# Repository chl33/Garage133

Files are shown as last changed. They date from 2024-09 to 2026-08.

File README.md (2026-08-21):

# Garage133

**Garage133** is a DIY garage door automation and monitoring system based on the ESP32.
It provides capability to remotely control up to two garage doors, monitor their
 state (open/closed), detect vehicle presence, measure environmental conditions
 (temperature/humidity), and detect motion within the garage.

The system is designed to integrate seamlessly with **Home Assistant** via MQTT
 but also provides a modern, responsive **Svelte-based Web Interface** for control and configuration.

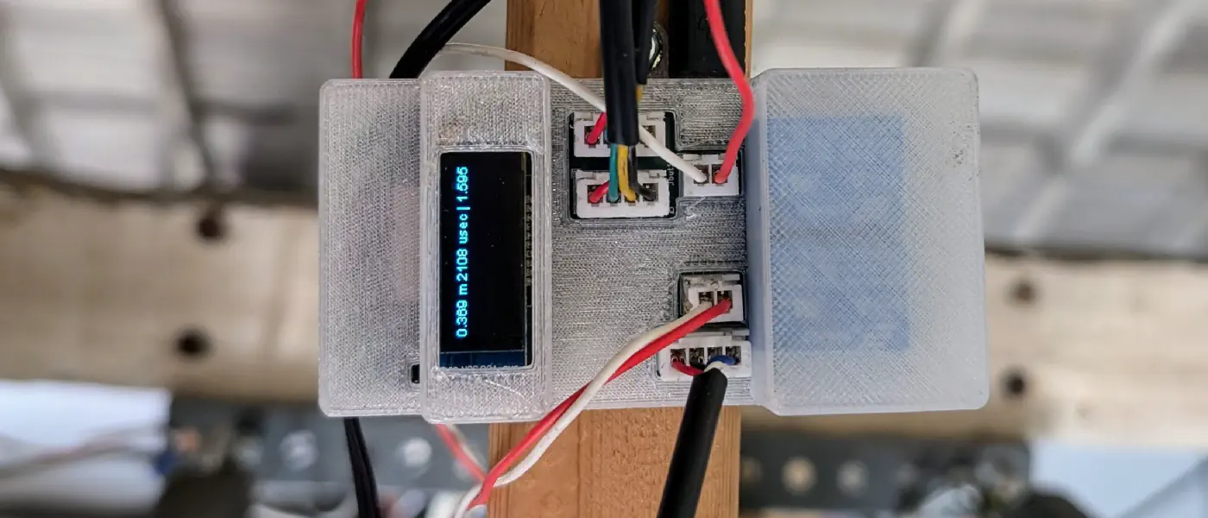
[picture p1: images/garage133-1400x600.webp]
Garage133


## What's New in v1.0.3

*   **Modernized API**: Full transition to `camelCase` JSON keys for all status and configuration endpoints, enabling simpler and more robust integration with the Svelte frontend.
*   **og3 v0.6.0 Core**: Leveraging the latest framework improvements, including declarative `require()` dependencies and optimized memory management.
*   **Automatic Build Pipeline**: Frontend assets are now automatically rebuilt during the PlatformIO compilation process.
*   **Coding and infrastructure cleanups**: Linting, CI, coding improvements.

## Features

*   **Dual Door Control:** Independent control for two garage doors using relays.
*   **HMM State Estimation:** Uses **Hidden Markov Models (HMM)** and sonar sensors to robustly determine door and car states:
    *   **Open** (Door is rolled up).
    *   **Closed with Car** (Door is down, vehicle detected).
    *   **Closed (Empty)** (Door is down, bay is empty).
*   **Modern Web Dashboard:** A responsive Svelte SPA to:
    *   Monitor real-time sensor data and door status.
    *   Trigger door relays remotely.
    *   Visualize HMM detection probabilities.
    *   Manually correct/label states to refine detection.
    *   Upload and reload HMM JSON models dynamically.
*   **Environmental Monitoring:** SHTC3 sensor for Temperature and Humidity.
*   **Motion Detection:** PIR sensor integration.
*   **Light Monitoring:** Analog light sensor to detect garage lighting levels.
*   **Home Assistant:** Native MQTT Discovery support for easy integration.
*   **OLED Display:** Shows status, IP address, and sensor readings locally.
*   **OTA Updates:** Support for reliable Over-The-Air firmware updates using expanded flash partitions.

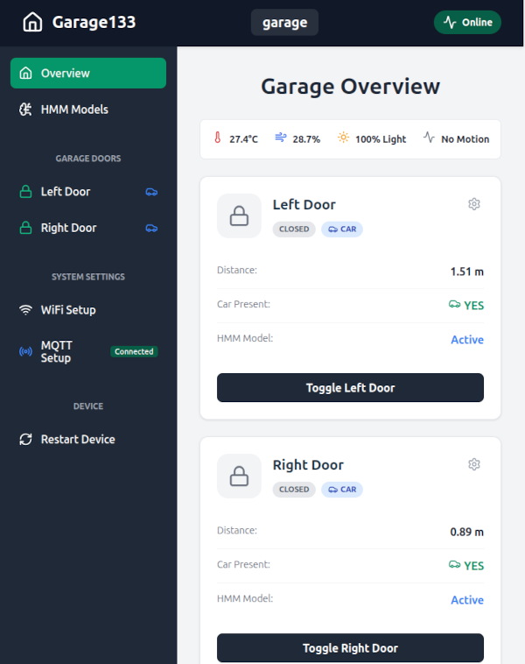
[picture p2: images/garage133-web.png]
Web interface


## Hardware

The project is built around an **ESP32** (Node32s / ESP32 Dev Module).

### Pinout Configuration

| Component | Pin (ESP32) | Description |
| :--- | :--- | :--- |
| **Relay (Left)** | GPIO 15 | Control for Left Garage Door |
| **Relay (Right)** | GPIO 2 | Control for Right Garage Door |
| **Sonar Trigger (Left)** | GPIO 16 | HC-SR04 Trigger |
| **Sonar Echo (Left)** | GPIO 17 | HC-SR04 Echo |
| **Sonar Trigger (Right)** | GPIO 5 | HC-SR04 Trigger |
| **Sonar Echo (Right)** | GPIO 18 | HC-SR04 Echo |
| **PIR Sensor** | GPIO 25 | Motion Detection |
| **Light Sensor** | GPIO 33 | Analog Light Level |
| **I2C SDA** | GPIO 21 | SHTC3 & OLED Display |
| **I2C SCL** | GPIO 22 | SHTC3 & OLED Display |

*Note: Pin definitions can be found in `src/main.cpp`.*

### Fabrication
This repository includes files for fabricating the custom PCB and 3D printed case:
*   **KiCAD:** Circuit board designs are located in the `KiCAD/` directory.
*   **3D Parts:** OpenSCAD and STL files for the enclosure and sensor mounts are
     in the `scad/` directory.

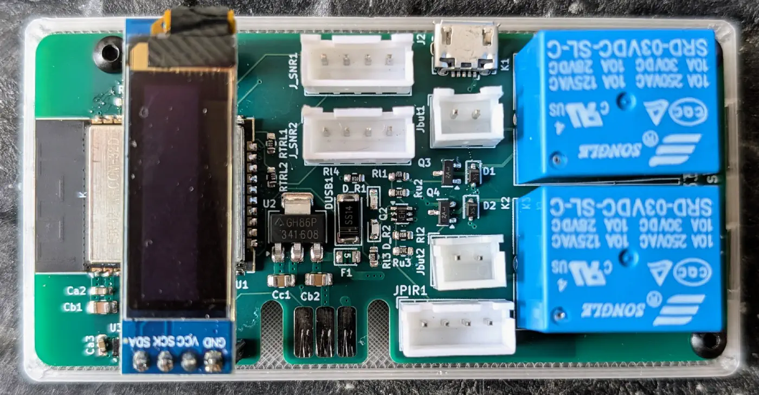
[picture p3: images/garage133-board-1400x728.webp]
Garage133 board

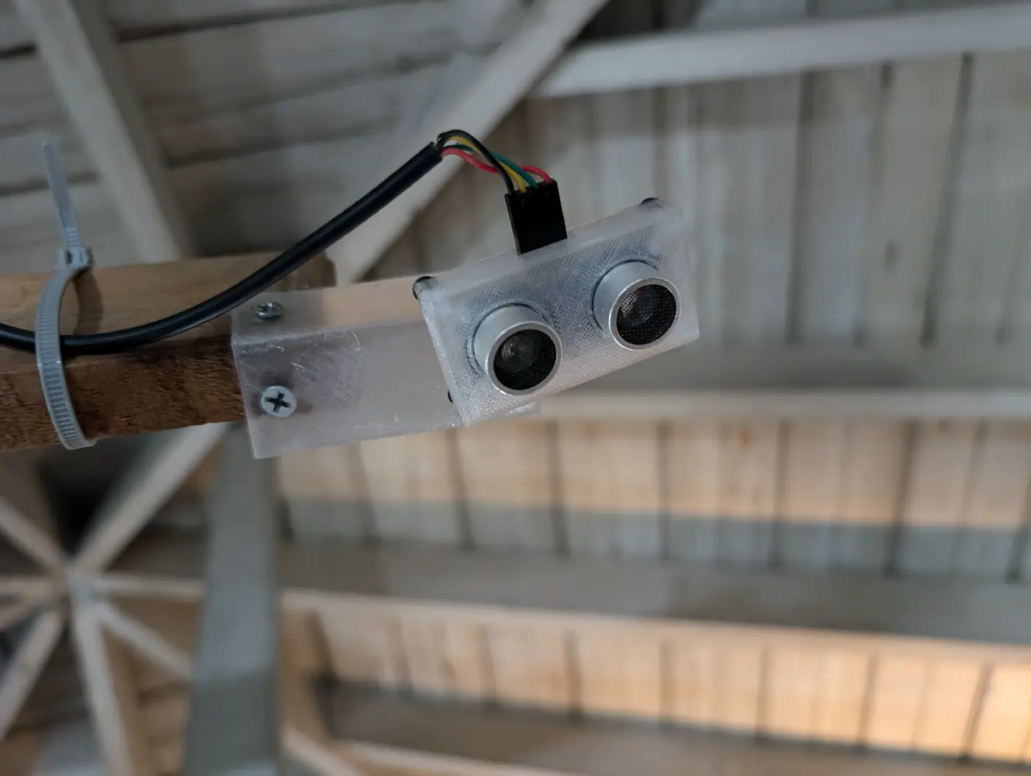
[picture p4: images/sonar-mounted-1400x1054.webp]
Sonar sensor


My sonar sensor mount design is
 [published on printables](https://www.printables.com/model/1741349-sonar-ball-and-socket-mount).

## Getting Started

### Prerequisites
*   [PlatformIO](https://platformio.org/) (VSCode Extension or CLI)
*   [Node.js & npm](https://nodejs.org/) (For building the Web Interface)
*   Git

### Installation

1.  **Clone the repository:**
    ```bash
    git clone https://github.com/chl33/Garage133.git
    cd Garage133
    ```

2.  **Build the Web Interface:**
    Generate the C++ header containing the Svelte assets:
    ```bash
    ./build-svelte.sh
    ```

3.  **Configuration:**
    Copy the example secrets file and configure your environment settings.
    ```bash
    cp secrets.ini.example secrets.ini
    ```
    Edit `secrets.ini` to set your upload port, UDP log target, and OTA password.

-    *Note: WiFi and MQTT credentials can be configured via the captive portal on
-	 first boot, when you attach to the board's WiFi network named 'garage133.'
     They can be configured via the web dashboard therafter.*

4.  **Build and Flash:**
    Connect your ESP32 via USB for the first flash (to apply the `min_spiffs` partition table).
    ```bash
    pio run -e usb_node32s --target upload
    ```

## Usage

### Web Interface
Once connected to WiFi, navigate to the device's IP address in your browser.
*   **Overview:** Real-time status of both doors and environment.
*   **Door Details:** Click the Gear icon on a door card to see HMM probabilities, manually label the current state, or upload a new model.
*   **Settings:** Configure WiFi, MQTT, and restart the device.

### Home Assistant
Ensure your Home Assistant instance has an MQTT broker configured.
The device uses Home Assistant MQTT Discovery. Once the device connects to your MQTT broker, the following entities should automatically appear:
*   **Covers:** `left_door`, `right_door` (Open/Close control)
*   **Sensors:** `temperature`, `humidity`, `light`
*   **Binary Sensors:** `car` (presence for each bay), `motion`

### HMM Analysis Toolkit
The `analysis/` directory contains Python tools to help refine your detection models:
*   Download historical sonar data from InfluxDB, if you have this setup.
*   Train HMM models using the Viterbi algorithm.
*   Evaluate and export models to JSON for upload to the device.

## Blog Post
For a more detailed write-up on the background and design of this project, please see the [blog post](https://selectiveappeal.org/posts/garage133/).

## License
This project is licensed under the MIT License - see the [LICENSE](LICENSE) file for details.

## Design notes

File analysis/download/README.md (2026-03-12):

# InfluxDB Data Downloader

This tool downloads sonar sensor data (or any other entity) from InfluxDB for a specified time range and saves it to a CSV file, suitable for analysis and model training (e.g., HMMs).

## Setup

1.  Navigate to this directory:
    ```bash
    cd analysis/download
    ```
2.  Install dependencies using Poetry:
    ```bash
    poetry install
    ```

## Usage

Run the script via `poetry run`:

```bash
poetry run python src/download/download.py \
    --start "2026-02-01T00:00:00Z" \
    --end "2026-02-25T23:59:59Z" \
    --entity "garage_measured_distance" \
    --output "sonar_training_data.csv"
```

### Parameters:
*   `--start`: ISO8601 start timestamp (UTC).
*   `--end`: ISO8601 end timestamp (UTC).
*   `--entity`: The `entity_id` tag in InfluxDB (default: `garage_measured_distance`).
*   `--output`: Filename for the resulting CSV (default: `sonar_data.csv`).

## Configuration
The script uses the following defaults (found in `download.py`):
*   **Host:** `influxdb.go-robo.net`
*   **Database:** `Home Assistant`
*   **Token:** Can be set via the `INFLUX_TOKEN` environment variable.

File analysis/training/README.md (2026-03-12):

# Garage133 Training Module

This module trains a Hidden Markov Model (HMM) to classify garage states (Open, Closed+Car, Closed+Empty) based on sonar distance readings. It generates side-specific models (`hmm_left.json` and `hmm_right.json`) that can be uploaded directly to the ESP32.

## Setup

Ensure you have Poetry installed, then run:

```bash
poetry install
```

## Training the Model

To train side-specific models using a labeled manifest:

```bash
poetry run python src/training/train_hmm.py --manifest manifest.yaml --output-dir .
```

### Advanced Training Options
*   **Granular Bucketing**: Instead of manual boundaries, you can generate evenly spaced buckets to capture a more detailed "fingerprint" of the garage states.
    ```bash
    poetry run python src/training/train_hmm.py --num-buckets 10 --max-dist 400
    ```
    *   `--num-buckets`: Number of distance ranges to use (e.g., 10).
    *   `--max-dist`: The maximum expected distance in cm (e.g., 400). Readings beyond this will fall into an "Error/Reflection" bucket.
*   **Manual Boundaries**: 
    ```bash
    poetry run python src/training/train_hmm.py --boundaries 70 190 350
    ```

## Testing and Validation

### Individual Episode Test
To visualize the performance on a specific episode:
```bash
poetry run python src/training/test_hmm.py --model-dir . --manifest manifest.yaml --episode 0 --probs
```
*   `--probs`: Show internal state probabilities (confidence) over time.

### Global Performance Characterization
To characterize how well your model performs across **every episode** in your manifest at once:
```bash
poetry run python src/training/test_hmm.py --model-dir . --manifest manifest.yaml --all
```

**What this provides:**
*   **Global Accuracy**: A single percentage representing performance across all your collected data.
*   **Global Confusion Matrix**: An aggregated matrix that highlights systematic errors (e.g., if the model frequently confuses "Car" and "Empty" across multiple days).

### Understanding the Metrics
*   **Accuracy**: The percentage of sonar samples correctly classified.
*   **Confusion Matrix**: Rows represent the actual state (Ground Truth), and columns represent what the HMM predicted.
    *   *Diagonal entries* (top-left to bottom-right) represent correct classifications.
    *   *Off-diagonal entries* show exactly which states are being confused.

## Data Organization

The trainer expects a `manifest.yaml` file that points to CSV files containing sonar data. Use the `interactive.py` tool in the `download` module to generate and label these episodes.

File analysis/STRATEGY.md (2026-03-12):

# Garage133: HMM Classification Strategy

This document outlines the strategy for replacing distance-threshold-based logic with a Hidden Markov Model (HMM) for garage door and car presence classification.

## 1. State Definition
Each side of the garage is modeled independently with three hidden states:
1.  **`OPEN`**: The garage door is rolled up, typically resulting in very close sonar readings (< 60cm).
2.  **`CLOSED_CAR`**: The door is shut and a vehicle is present. Readings are in the middle range (e.g., 80cm – 180cm).
3.  **`CLOSED_EMPTY`**: The door is shut and no vehicle is present. Readings are far (e.g., > 200cm, bouncing off the floor).

## 2. Emission Model: Discrete Buckets
To ensure robustness against sensor noise and ease of implementation on the ESP32, we use **Discrete Emissions**:
*   Raw sonar readings (cm) are mapped into buckets (e.g., 0, 1, 2, 3).
*   **Bucket 0 (Near):** 0 – 70cm
*   **Bucket 1 (Mid):** 70 – 190cm
*   **Bucket 2 (Far):** 190 – 350cm
*   **Bucket 3 (Error/Long):** > 350cm

The HMM learns the probability of seeing each bucket while in each hidden state. For example, in state `OPEN`, the probability of Bucket 0 is very high (~0.95), while Bucket 2 is near zero.

## 3. Transition Model & Priors
Training data consists of short "episodes" (e.g., a car entering). This data is **not representative** of a full 24-hour cycle. To avoid a biased model:
*   **Learn Emissions from Data:** Use the episodes to calculate the mean/variance or bucket distributions for each state.
*   **Hard-code Transitions (Priors):** Manually define the transition matrix based on physical reality:
    *   `CLOSED_EMPTY` cannot transition to `CLOSED_CAR` without passing through `OPEN`.
    *   Stay-probabilities should be high (e.g., 0.999) to provide "hysteresis" and filter out transient sensor errors.

## 4. Data Organization: The Manifest
Training data is managed via a central `manifest.yaml`. This keeps raw CSVs immutable and allows for easy re-labeling.

### Manifest Structure
```yaml
episodes:
  - file: "raw/event_001.csv"
    left:
      initial_state: "closed_empty"
      transitions:
        - { time: "2026-02-27T10:00:05Z", to: "open" }
        - { time: "2026-02-27T10:01:00Z", to: "closed_car" }
    right:
      initial_state: "closed_car"
      transitions: []
```

## 5. Workflow
1.  **Collection:** Use `download.py` to fetch data from InfluxDB. Provide state labels during download to auto-populate the manifest.
2.  **Training:** A Python script reads the manifest, processes CSVs, and calculates HMM parameters (Transition Matrix $A$, Emission Matrix $B$, Initial Probabilities $\pi$).
3.  **Deployment:** Export parameters to a C++ header (`hmm_config.h`) for the ESP32.
4.  **Refinement:** If the ESP32 fails, download that specific time range, label it correctly in the manifest, and retrain.

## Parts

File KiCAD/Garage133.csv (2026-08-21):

Reference | Qty | Value | DNP | Exclude from BOM | Exclude from Board | Footprint
Ca1,Ca2,Ca3 | 3 | 100nF |  |  |  | Capacitor_SMD:C_0603_1608Metric
Cb1,Cb2 | 2 | 10uF |  |  |  | Capacitor_SMD:C_0805_2012Metric_Pad1.18x1.45mm_HandSolder
Cc1 | 1 | 47uF |  |  |  | Capacitor_SMD:C_0805_2012Metric_Pad1.18x1.45mm_HandSolder
D1,D2 | 2 | D |  |  |  | Diode_SMD:D_SOD-323
DUSB1 | 1 | SS14 |  |  |  | Diode_SMD:D_2010_5025Metric
D_R1 | 1 | RED |  |  |  | LED_SMD:LED_0603_1608Metric
D_R2 | 1 | BLU |  |  |  | LED_SMD:LED_0603_1608Metric
F1 | 1 | 0.5A |  |  |  | Diode_SMD:D_0805_2012Metric
J1 | 1 | Edge2x6_Connector |  |  |  | chl33_library:EdgeConnector_2x3
J2 | 1 | USB_B_Micro |  |  |  | Connector_USB:USB_Micro-B_Amphenol_10118194_Horizontal
Jbut1,Jbut2 | 2 | Conn_01x02 |  |  |  | Connector_JST:JST_XH_B2B-XH-A_1x02_P2.50mm_Vertical
JOLED1 | 1 | Conn_01x04_Socket |  |  |  | Connector_PinSocket_2.54mm:PinSocket_1x04_P2.54mm_Vertical
JPIR1,J_SNR1,J_SNR2,J_SNR3,J_SNR4 | 5 | Conn_01x04_Pin |  |  |  | Connector_JST:JST_XH_B4B-XH-A_1x04_P2.50mm_Vertical
K1,K2 | 2 | SANYOU_SRD_Form_C |  |  |  | Relay_THT:Relay_SPDT_SANYOU_SRD_Series_Form_C
Q2 | 1 | UMH3N |  |  |  | Package_TO_SOT_SMD:SOT-363_SC-70-6
Q3,Q4 | 2 | MMBT3906 |  |  |  | Package_TO_SOT_SMD:SOT-23
R2l1,R2l2,R2l3,R2l4,Rf1,Rf2 | 6 | 2.2k |  |  |  | Resistor_SMD:R_0603_1608Metric
R3l1,R3l2,R3l3,R3l4 | 4 | 3.3k |  |  |  | Resistor_SMD:R_0603_1608Metric
Rl1,Rl2,Rl3,Rl4,RTRL1,RTRL2,RTRL3,RTRL4 | 8 | 1k |  |  |  | Resistor_SMD:R_0603_1608Metric
Rt1 | 1 | 470 |  |  |  | Resistor_SMD:R_0603_1608Metric
Ru1,Ru2,Ru3 | 3 | 10k |  |  |  | Resistor_SMD:R_0603_1608Metric
U1 | 1 | ESP32-WROOM-32 |  |  |  | RF_Module:ESP32-WROOM-32
U2 | 1 | AMS1117-3.3 |  |  |  | Package_TO_SOT_SMD:SOT-223-3_TabPin2
U3 | 1 | SHTC3 |  |  |  | Sensor_Humidity:Sensirion_DFN-4-1EP_2x2mm_P1mm_EP0.7x1.6mm

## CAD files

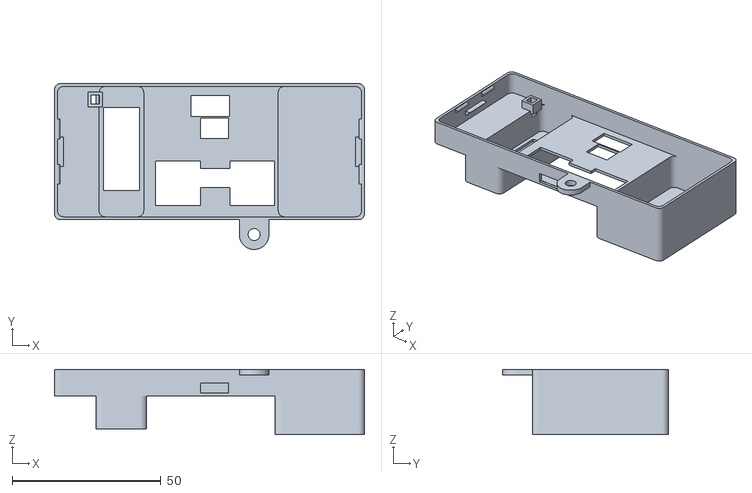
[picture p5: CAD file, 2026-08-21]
scad/box/box_top.stl
104.2 x 55.8 x 22.0

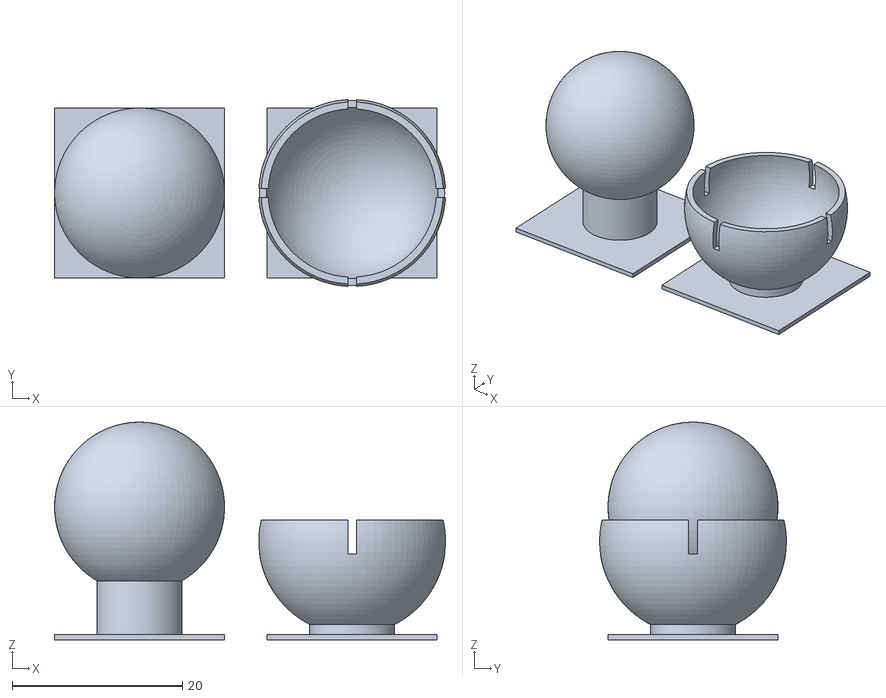
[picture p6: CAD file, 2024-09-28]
scad/SonarBox/ball_and_socket.stl
46.0 x 21.9 x 25.6

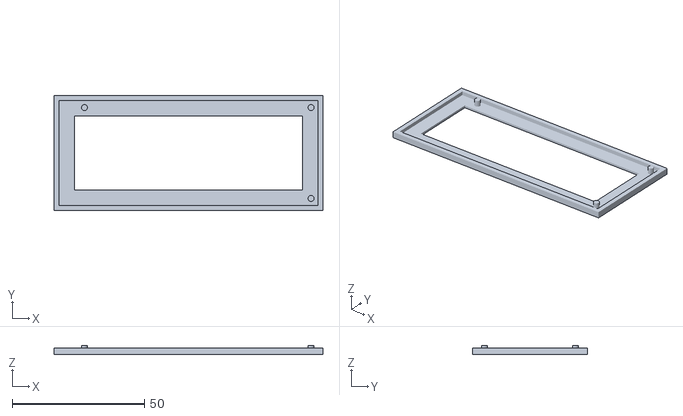
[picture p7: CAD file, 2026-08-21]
scad/stencil_fixture/stencil_fixture.stl
101.8 x 43.4 x 3.59

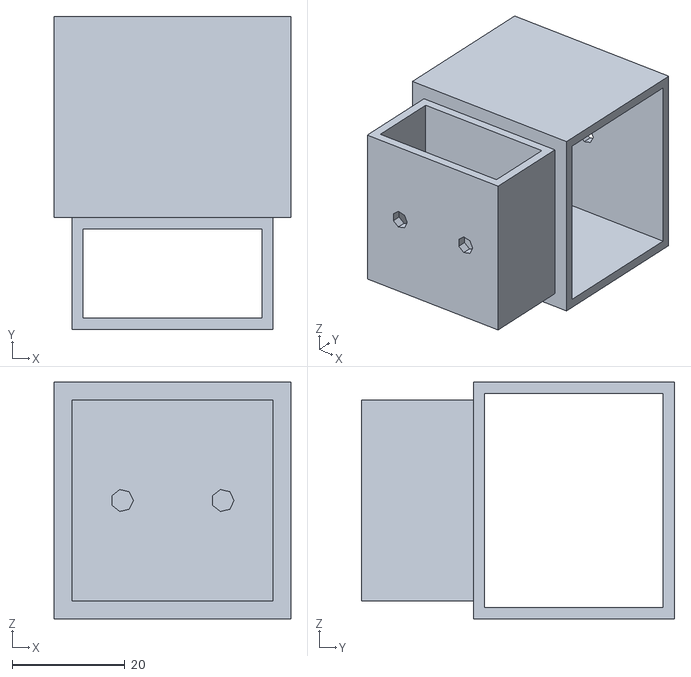
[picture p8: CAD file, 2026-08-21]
scad/t_joint/t_joint.stl
42.1 x 55.6 x 42.1

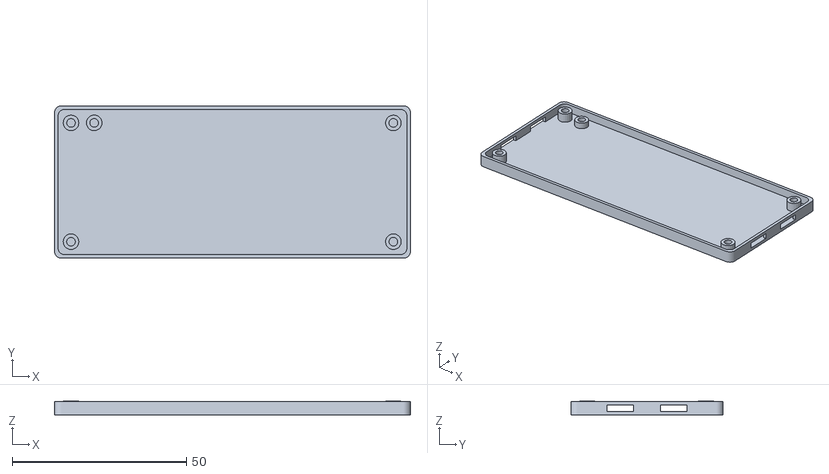
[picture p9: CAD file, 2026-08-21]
scad/box/box_bottom.stl
102.2 x 43.8 x 4.00

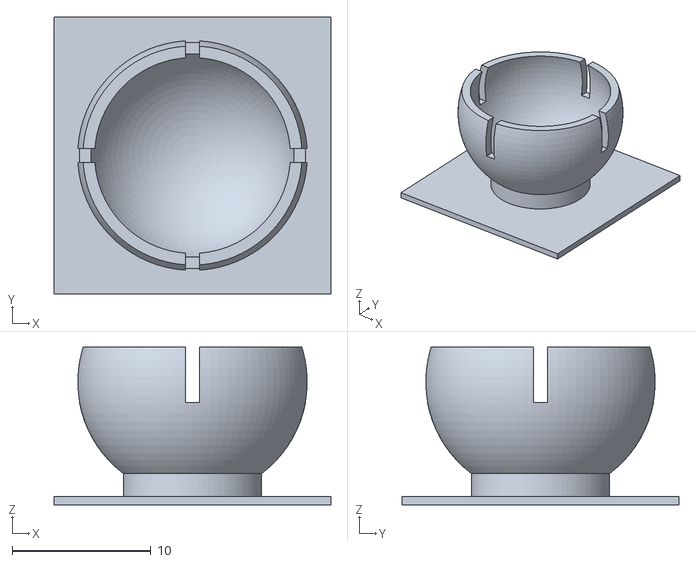
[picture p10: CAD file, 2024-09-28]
scad/SonarBox/socket_test.stl
20.0 x 20.0 x 11.4

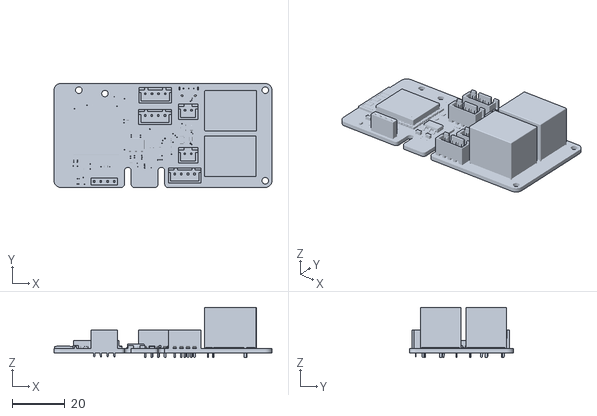
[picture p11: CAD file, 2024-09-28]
scad/box/Garage133.stl
82.5 x 39.4 x 19.0

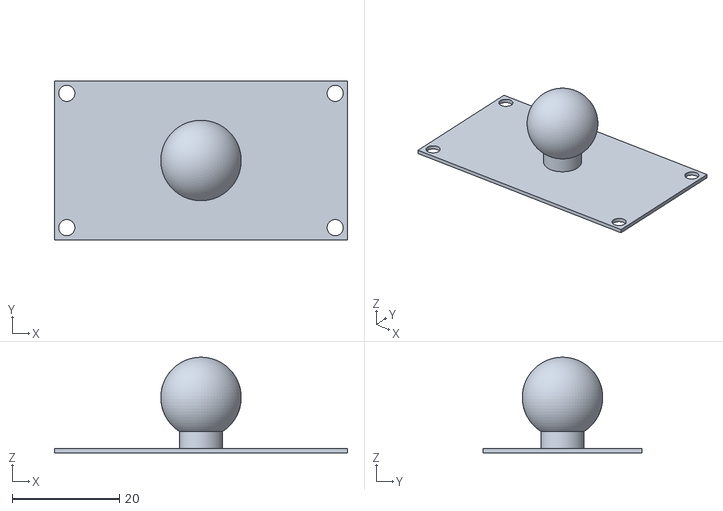
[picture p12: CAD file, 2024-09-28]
scad/SonarBox/sonar_box_bottom.stl
54.6 x 29.6 x 17.8

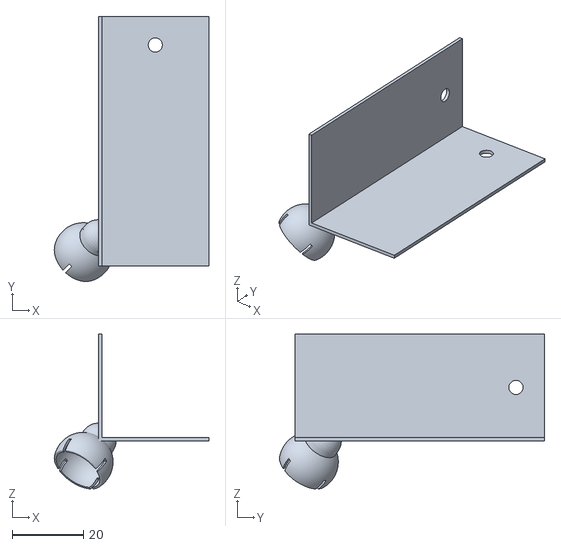
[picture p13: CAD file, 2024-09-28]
scad/SonarBox/socket_mount.stl
43.4 x 74.4 x 43.5

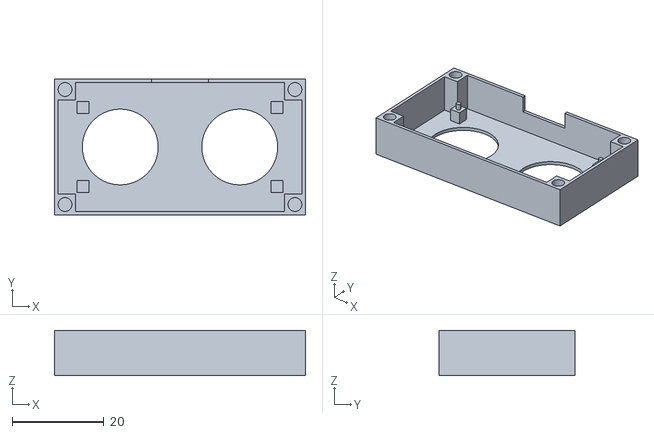
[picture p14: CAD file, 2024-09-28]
scad/SonarBox/sonar_box_top.stl
54.6 x 29.6 x 9.79

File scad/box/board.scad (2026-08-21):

// Copyright (c) 2026 Chris Lee and contributors.
// Licensed under the MIT license. See LICENSE file in the project root for details.

include <ProjectBox/project_box.scad>

board_thickness = 1.6;
pad_space = 2.54;
board_dims = [ 97.79, 39.37, board_thickness];

module Garage133_board() {
  u = pad_space;

  // Board imported from KiCad (VRML) -> Blender
  translate([board_dims[0]/2, board_dims[1]/2, board_dims[2]/2]) color("white")
    import(file="../../KiCAD/Garage133.stl", convexity=3);

}

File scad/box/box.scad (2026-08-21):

// Copyright (c) 2026 Chris Lee and contributors.
// Licensed under the MIT license. See LICENSE file in the project root for details.

include <ProjectBox/project_box.scad>
include <ProjectBox/mounts.scad>
include <ProjectBox/oled91.scad>
include <ProjectBox/shtc3_window.scad>
include <board.scad>

ones = [1, 1, 1];

wall_thickness = 1;
gap = 0.2;
corner_radius = 2;

mount_offset = pad_space;
space_above_board = 2;
space_below_board = 3;
inner_dims = (board_dims
	      + Z*(space_above_board+space_below_board)
	      + 2*gap*ones);
outer_dims = (inner_dims
	      + 2*ones*wall_thickness
	      + [2, 2, 0] * corner_radius);

// cutout for oled screen
oled_o = [16.5, 8];
oled_d = [12, 28];
sonar_co1_o = [34, 26];
sonar_co1_d = [15, 15];
sonar_co2_o = [59, 26];
sonar_co2_d = [15, 15];
relay1_co_o = [48, 28.5];
relay1_co_d = [11, 6.5];
relay2_co_o = [49, 11.5];
relay2_co_d = [9.5, 7];
pirl_co_o = [45.8, 4];
pirl_co_d = [13., 7];

top_cutouts = [[oled_o, oled_d],
	       [sonar_co1_o, sonar_co1_d],
	       [sonar_co2_o, sonar_co2_d],
	       [relay1_co_o, relay1_co_d],
	       [relay2_co_o, relay2_co_d],
	       [pirl_co_o, pirl_co_d],
	       ];

usb_cutout = [[45.7, wall_thickness+space_below_board+board_thickness-1], [9.5, 3.5]];
yp_cutouts = [usb_cutout];

// humps is a list of [offset-xy, outer_dims]
oled_ho = [14, 0];
oled_hd = [17, outer_dims[1], 12];
relay_hd = [30, outer_dims[1], 14];
relay_ho = [outer_dims[0]-relay_hd[0], 0];
humps = [[oled_ho, oled_hd], [relay_ho, relay_hd]];

module in_Garage133_board_frame(board_height=false) {
  zoffset = wall_thickness + (board_height ? space_below_board + 2*gap + board_thickness : 0);
  //  zoffset = wall_thickness + (board_height ? space_below_board : 0);
  in_board_frame(outer_dims, board_dims, zoffset) children();
}
module Garage133_box(top) {
  wall = wall_thickness;
  shtc3_loc = [9, 0.6, 0];

  difference() {
    union() {
      project_box(outer_dims,
		  wall_thickness=wall_thickness,
		  gap=gap,
		  snaps_on_sides=true,
		  top_cutouts=top_cutouts,
		  yp_cutouts=yp_cutouts,
		  corner_radius=corner_radius,
		  humps=humps,
		  top=top);
      if (top) {
	in_Garage133_board_frame(board_height=true)
	  shtc3_window(shtc3_loc, space_above_board+wall, wall, false, z_gap=-1);
	screw_tab_d = 10;
	translate([outer_dims[0]/2+15, outer_dims[1], 0])
	  screw_tab(tab_width=screw_tab_d, thickness=2*wall, screw_radius=2);
      } else {
	// Stuff to add on bottom.
	in_Garage133_board_frame() {
	  at_corners(board_dims+1.0*X, mount_offset, x_extra=-1.2, y_extra=-0.2)
	    screw_mount(space_below_board, wall, 2.5/2);
	}
	translate([12.4, outer_dims[1]-pad_space*2.33, 0])
	  screw_mount(space_below_board, wall, 2.5/2);
      }
    }
    // Cut outs.
    if (top) {
      in_Garage133_board_frame(board_height=true)
	shtc3_window(shtc3_loc, space_above_board+wall, wall, true, z_gap=-1);
    }
  }
}

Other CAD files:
scad/box/box_bottom.scad
scad/box/box_top.scad
scad/SonarBox/ball_and_socket.scad
scad/SonarBox/socket_mount.scad
scad/SonarBox/socket_test.scad
scad/SonarBox/sonar_box.scad
scad/SonarBox/sonar_box_bottom.scad
scad/SonarBox/sonar_box_test.scad
scad/SonarBox/sonar_box_top.scad
scad/box/Garage133_test.scad
scad/box/gui.scad
scad/stencil_fixture/stencil_fixture.scad
scad/t_joint/t_joint.scad

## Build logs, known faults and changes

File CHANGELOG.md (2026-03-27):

# Changelog

All notable changes to this project will be documented in this file.

The format is based on [Keep a Changelog](https://keepachangelog.com/en/1.0.0/),
and this project adheres to [Semantic Versioning](https://semver.org/spec/v2.0.0.html).

## [1.0.3] - 2026-03-24

### Added
- **Declarative Dependency Management**: Refactored core modules to use the new `og3` `require<T>()` pattern, simplifying internal module linking and improving boot-time memory efficiency.
- **Svelte-Native JSON API**: Transitioned all status and configuration JSON keys to `camelCase` (e.g., `ipAddr`, `wifiPassword`, `mqttConnected`) to align with JavaScript/TypeScript standards and simplify the Svelte store logic.

### Changed
- **Framework Upgrade**: Bumped to **og3 v0.6.0**.
- **Enhanced API Handlers**: Re-implemented web API endpoints using the unified `NetRequest` and `NetResponse` abstraction layer for better portability and robustness.
- **Automatic Svelte Builds**: Integrated `build_svelte.py` into the PlatformIO lifecycle to ensure the web interface is always in sync with the firmware during the build process.
*   **Coding and infrastructure cleanups**: Linting, CI, coding improvements.

## [1.0.0] - 2026-03-10

### Added
- **Svelte Web Interface**
  - Responsive Single Page Application (SPA) dashboard for real-time monitoring.
  - Individual door detail pages with HMM probability visualizations.
  - Integrated manual state correction/labeling to refine detection logic.
  - Robust networking with `AbortController` timeouts and sequential polling.
- **HMM State Estimation**
  - Implemented Hidden Markov Models (HMM) for robust classification of door and car states.
  - Web-based management for uploading and reloading HMM JSON models.
  - Python-based analysis toolkit for data downloading and model training.
- **Modernized Networking**
  - Integrated `PsychicHttp` for a modernized Request/Response web server model.
  - Switched to `PsychicMqttClient` for improved MQTT reliability on ESP32.

### Changed
- **Infrastructure & Framework**
  - Upgraded to **og3 v0.5.0** and its ecosystem libraries.
  - Expanded flash partitions to `min_spiffs.csv` (1.9MB App space) to support richer UI and reliable OTA.
  - Moved legacy UI to `/root` and registered Svelte SPA as the primary interface.
  - Optimized build system with `build-svelte.sh` for automated asset generation.
- **Dependency Management**
  - Transitioned to registry-based dependencies with deep transitive resolution.

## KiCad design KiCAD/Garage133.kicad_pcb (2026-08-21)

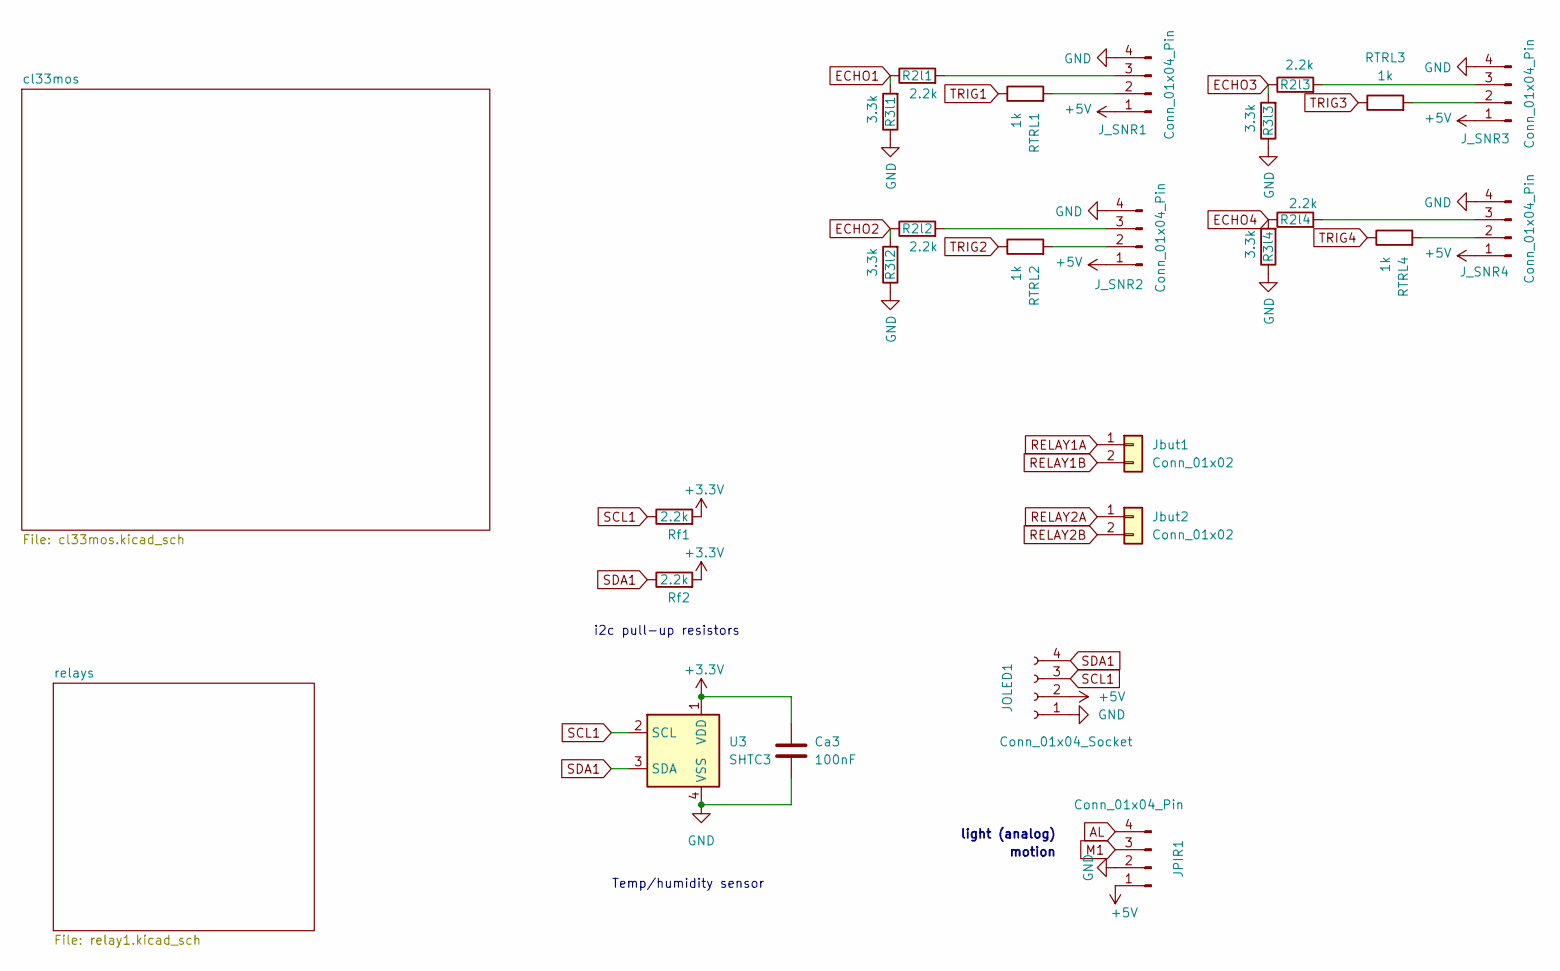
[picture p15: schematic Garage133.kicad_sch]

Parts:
Ca3: 100nF; C_0603_1608Metric
JOLED1: Conn_01x04_Socket; PinSocket_1x04_P2.54mm_Vertical
JPIR1: Conn_01x04_Pin; JST_XH_B4B-XH-A_1x04_P2.50mm_Vertical
J_SNR1, J_SNR2, J_SNR3, J_SNR4: Conn_01x04_Pin; JST_XH_B4B-XH-A_1x04_P2.50mm_Vertical
Jbut1, Jbut2: Conn_01x02; JST_XH_B2B-XH-A_1x02_P2.50mm_Vertical
R2l1, R2l2, R2l3, R2l4: 2.2k; R_0603_1608Metric
R3l1, R3l2, R3l3, R3l4: 3.3k; R_0603_1608Metric
RTRL1, RTRL2, RTRL3, RTRL4: 1k; R_0603_1608Metric
Rf1, Rf2: 2.2k; R_0603_1608Metric
U3: SHTC3; Sensirion_DFN-4-1EP_2x2mm_P1mm_EP0.7x1.6mm

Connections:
+3.3V: Ca3.1, Rf1.2, Rf2.2, U3.1 (VDD); also elsewhere on the board
+5V: JOLED1.2, JPIR1.1, J_SNR1.1, J_SNR2.1, J_SNR3.1, J_SNR4.1; also elsewhere on the board
AL: JPIR1.4; also elsewhere on the board
ECHO1: R2l1.1, R3l1.2; also elsewhere on the board
ECHO2: R2l2.1, R3l2.2; also elsewhere on the board
ECHO3: R2l3.1, R3l3.2; also elsewhere on the board
ECHO4: R2l4.1, R3l4.2; also elsewhere on the board
GND: Ca3.2, JOLED1.1, JPIR1.2, J_SNR1.4, J_SNR2.4, J_SNR3.4, J_SNR4.4, R3l1.1, R3l2.1, R3l3.1, R3l4.1, U3.4 (VSS); also elsewhere on the board
M1: JPIR1.3; also elsewhere on the board
unnamed: J_SNR1.2, RTRL1.2
unnamed: J_SNR1.3, R2l1.2
unnamed: J_SNR2.2, RTRL2.2
unnamed: J_SNR2.3, R2l2.2
unnamed: J_SNR3.2, RTRL3.2
unnamed: J_SNR3.3, R2l3.2
unnamed: J_SNR4.2, RTRL4.2
unnamed: J_SNR4.3, R2l4.2
RELAY1A: Jbut1.1; also elsewhere on the board
RELAY1B: Jbut1.2; also elsewhere on the board
RELAY2A: Jbut2.1; also elsewhere on the board
RELAY2B: Jbut2.2; also elsewhere on the board
SCL1: JOLED1.3, Rf1.1, U3.2 (SCL); also elsewhere on the board
SDA1: JOLED1.4, Rf2.1, U3.3 (SDA); also elsewhere on the board
TRIG1: RTRL1.1; also elsewhere on the board
TRIG2: RTRL2.1; also elsewhere on the board
TRIG3: RTRL3.1; also elsewhere on the board
TRIG4: RTRL4.1; also elsewhere on the board

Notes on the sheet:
Temp/humidity sensor
light (analog)
motion
i2c pull-up resistors

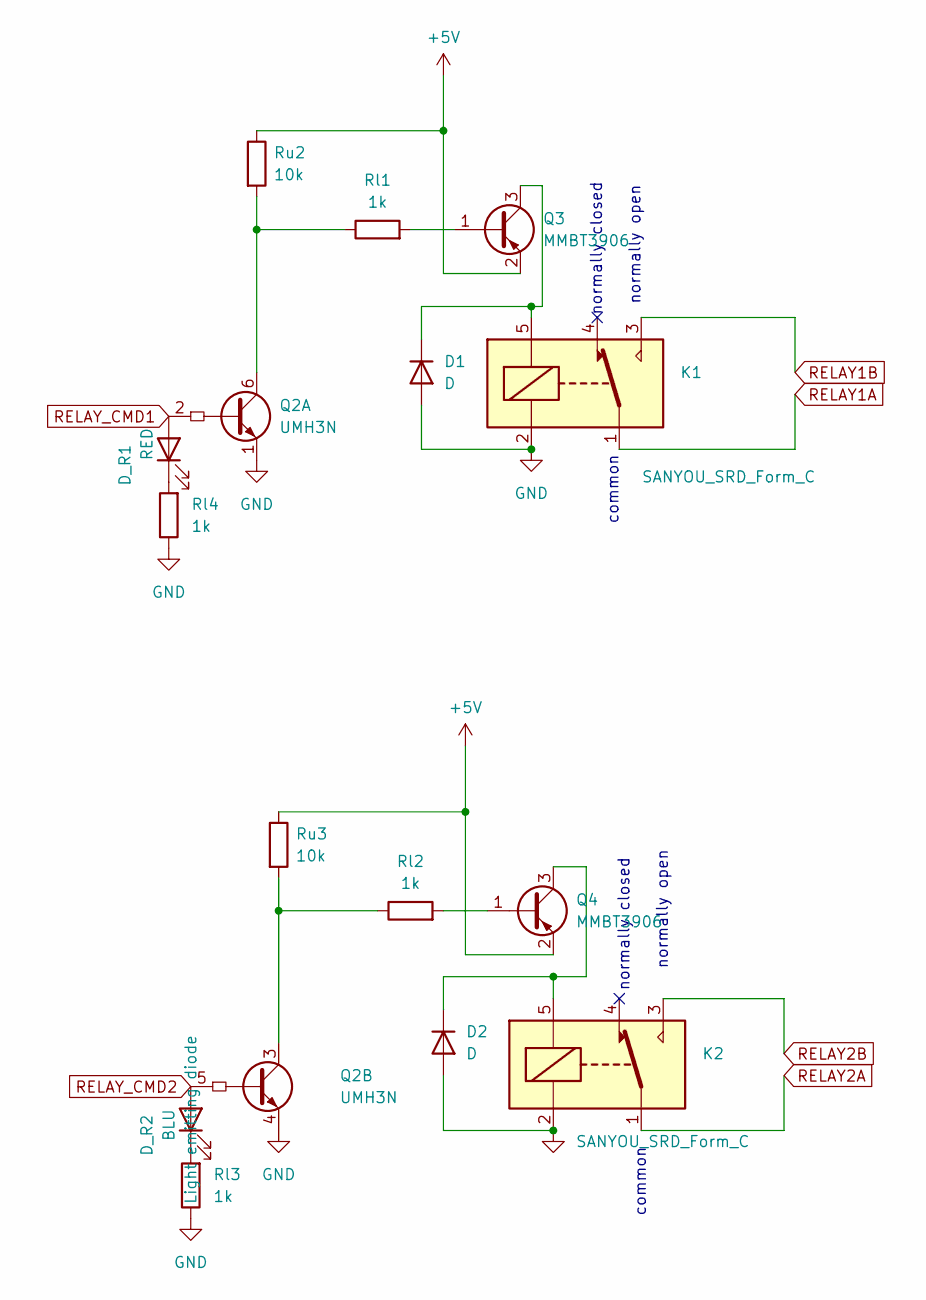
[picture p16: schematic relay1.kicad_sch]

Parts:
D1, D2: D; D_SOD-323
D_R1: RED; LED_0603_1608Metric
D_R2: BLU; LED_0603_1608Metric
K1, K2: SANYOU_SRD_Form_C; Relay_SPDT_SANYOU_SRD_Series_Form_C
Q2: UMH3N; SOT-363_SC-70-6
Q3, Q4: MMBT3906; SOT-23
Rl1, Rl2, Rl3, Rl4: 1k; R_0603_1608Metric
Ru2, Ru3: 10k; R_0603_1608Metric

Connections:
+5V: Q3.2 (E), Q4.2 (E), Ru2.1, Ru3.1; also elsewhere on the board
GND: D1.2 (A), D2.2 (A), K1.2, K2.2, Q2.1 (E1), Q2.4 (E2), Rl3.1, Rl4.1; also elsewhere on the board
unnamed: D1.1 (K), K1.5, Q3.3 (C)
unnamed: D2.1 (K), K2.5, Q4.3 (C)
unnamed: D_R1.1 (K), Rl4.2
unnamed: D_R2.1 (K), Rl3.2
unnamed: Q2.6 (C1), Rl1.1, Ru2.2
unnamed: Q2.3 (C2), Rl2.1, Ru3.2
unnamed: Q3.1 (B), Rl1.2
unnamed: Q4.1 (B), Rl2.2
RELAY1A: K1.1; also elsewhere on the board
RELAY1B: K1.3; also elsewhere on the board
RELAY2A: K2.1; also elsewhere on the board
RELAY2B: K2.3; also elsewhere on the board
RELAY_CMD1: D_R1.2 (A), Q2.2 (B1); also elsewhere on the board
RELAY_CMD2: D_R2.2 (A), Q2.5 (B2); also elsewhere on the board

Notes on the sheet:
normally closed
normally open
common

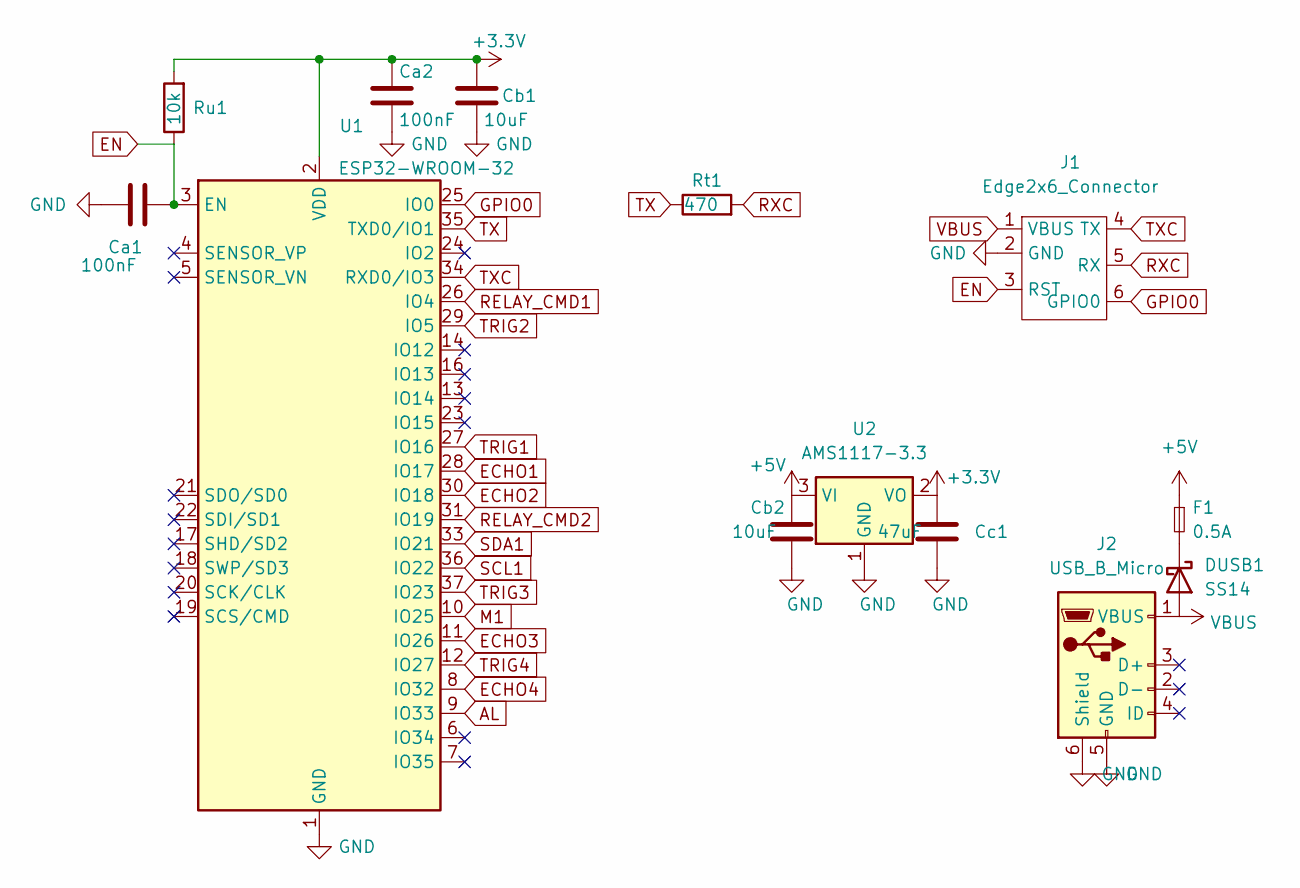
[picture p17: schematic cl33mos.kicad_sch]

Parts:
Ca1, Ca2: 100nF; C_0603_1608Metric
Cb1, Cb2: 10uF; C_0805_2012Metric_Pad1.18x1.45mm_HandSolder
Cc1: 47uF; C_0805_2012Metric_Pad1.18x1.45mm_HandSolder
DUSB1: SS14; D_2010_5025Metric
F1: 0.5A; D_0805_2012Metric
J1: Edge2x6_Connector; EdgeConnector_2x3
J2: USB_B_Micro; USB_Micro-B_Amphenol_10118194_Horizontal
Rt1: 470; R_0603_1608Metric
Ru1: 10k; R_0603_1608Metric
U1: ESP32-WROOM-32
U2: AMS1117-3.3; SOT-223-3_TabPin2

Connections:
+3.3V: Ca2.1, Cb1.1, Cc1.1, Ru1.2, U1.2 (VDD), U2.2 (VO); also elsewhere on the board
+5V: Cb2.1, F1.1, U2.3 (VI); also elsewhere on the board
AL: U1.9 (IO33); also elsewhere on the board
ECHO1: U1.28 (IO17); also elsewhere on the board
ECHO2: U1.30 (IO18); also elsewhere on the board
ECHO3: U1.11 (IO26); also elsewhere on the board
ECHO4: U1.8 (IO32); also elsewhere on the board
EN: Ca1.2, J1.3 (RST), Ru1.1, U1.3 (EN)
GND: Ca1.1, Ca2.2, Cb1.2, Cb2.2, Cc1.2, J1.2 (GND), J2.5 (GND), J2.6 (Shield), U1.1 (GND), U1.15 (GND), U1.38 (GND), U1.39 (GND), U2.1 (GND); also elsewhere on the board
GPIO0: J1.6 (GPIO0), U1.25 (IO0)
M1: U1.10 (IO25); also elsewhere on the board
unnamed: DUSB1.1 (K), F1.2
RELAY_CMD1: U1.26 (IO4); also elsewhere on the board
RELAY_CMD2: U1.31 (IO19); also elsewhere on the board
RXC: J1.5 (RX), Rt1.2
SCL1: U1.36 (IO22); also elsewhere on the board
SDA1: U1.33 (IO21); also elsewhere on the board
TRIG1: U1.27 (IO16); also elsewhere on the board
TRIG2: U1.29 (IO5); also elsewhere on the board
TRIG3: U1.37 (IO23); also elsewhere on the board
TRIG4: U1.12 (IO27); also elsewhere on the board
TX: Rt1.1, U1.35 (TXD0/IO1)
TXC: J1.4 (TX), U1.34 (RXD0/IO3)
VBUS: DUSB1.2 (A), J1.1 (VBUS), J2.1 (VBUS)

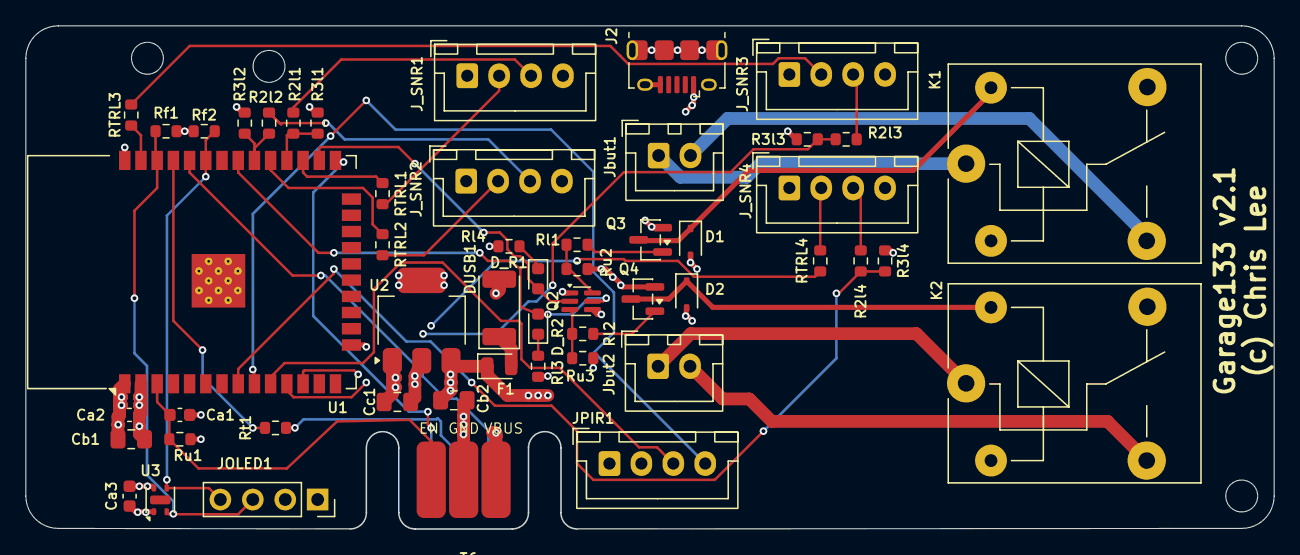
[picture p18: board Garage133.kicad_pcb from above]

Board: 4 copper layers, 97.8 x 39.4 mm, 52 parts (0 on the bottom side), 44 nets.

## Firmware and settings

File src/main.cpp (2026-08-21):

// Copyright (c) 2026 Chris Lee and contributors.
// Licensed under the MIT license. See LICENSE file in the project root for details.

#include <Arduino.h>
#include <LittleFS.h>
#include <WiFiClientSecure.h>
#include <og3/blink_led.h>
#include <og3/constants.h>
#include <og3/ha_app.h>
#include <og3/html_table.h>
#include <og3/mapped_analog_sensor.h>
#include <og3/motion_detector.h>
#include <og3/oled_wifi_info.h>
#include <og3/pir.h>
#include <og3/relay.h>
#include <og3/shtc3.h>
#include <og3/sonar.h>
#include <og3/units.h>
#include <og3/variable.h>
#include <og3/wifi_watchdog.h>

#include <algorithm>
#include <cstring>

#include "hmm.h"
#include "svelteesp32async.h"

#define VERSION "1.0.5"

namespace og3 {

static const char kManufacturer[] = "Chris Lee";
static const char kModel[] = "Garage133";
static const char kSoftware[] = "Garage133 v" VERSION;

// --- Garage133 Hardware Configuration ---

// Relays (Door Control)
const int kRelayLeftPin = 4;
const int kRelayRightPin = 19;

// Sonar Sensors
const int kLeftTrigPin = 16;
const int kLeftEchoPin = 17;
const int kRightTrigPin = 5;
const int kRightEchoPin = 18;

// Sonar Sensors (Rear - Sonar 2)
const int kLeftTrig2Pin = 23;
const int kLeftEcho2Pin = 26;
const int kRightTrig2Pin = 27;
const int kRightEcho2Pin = 32;

// PIR & Light Sensors
const int kPirPin = 25;
const int kLightPin = 33;

#if defined(LOG_UDP) && defined(LOG_UDP_ADDRESS)
constexpr App::LogType kLogType = App::LogType::kUdp;
#else
constexpr App::LogType kLogType = App::LogType::kSerial;
#endif

// Application and configuration.
WifiApp::Options s_app_options = WifiApp::Options()
                                     .withDefaultDeviceName("garage133")
                                     .withSoftwareName(kSoftware)
                                     .withApp(App::Options().withLogType(kLogType))
#if defined(LOG_UDP) && defined(LOG_UDP_ADDRESS)
                                     .withUdpLogHost(IPAddress(LOG_UDP_ADDRESS))
#endif
                                     .withOta(OtaManager::Options(OTA_PASSWORD));

HAApp::Options s_ha_options(kManufacturer, kModel, s_app_options);
HAApp s_app(s_ha_options);

// Variable Groups for MQTT/Discovery
VariableGroup s_garage_vg("garage", nullptr, 10);
VariableGroup s_left_vg("left", nullptr, 6);
VariableGroup s_right_vg("right", nullptr, 6);

// Relay and sensors.
Relay s_left_relay("left_relay", &s_app.tasks(), kRelayLeftPin, "left relay", true, s_garage_vg);
Relay s_right_relay("right_relay", &s_app.tasks(), kRelayRightPin, "right relay", true,
                    s_garage_vg);

MappedAnalogSensor::Options s_light_options = {
    .name = "light",
    .pin = static_cast<uint8_t>(kLightPin),
    .units = "percentage",
    .raw_description = "light raw",
    .description = "light %",
    .raw_var_flags = 0,
    .mapped_var_flags = 0,
    .config_flags = VariableBase::kConfig | VariableBase::Flags::kSettable,
    .default_in_min = 0,
    .default_in_max = 4095,
    .default_out_min = 100.0f,
    .default_out_max = 0.0f,
    .config_decimals = 1,
    .decimals = 1,
    .valid_in_min = 0,
    .valid_in_max = 4095,
};
VariableGroup s_light_cfg_vg("light_cfg");
MappedAnalogSensor s_light_sensor(s_light_options, &s_app.module_system(), s_light_cfg_vg,
                                  s_garage_vg);

Sonar s_left_sonar("left_sonar", kLeftTrigPin, kLeftEchoPin, &s_app.module_system(), s_garage_vg,
                   &s_app.ha_discovery());
Sonar s_right_sonar("right_sonar", kRightTrigPin, kRightEchoPin, &s_app.module_system(),
                    s_garage_vg, &s_app.ha_discovery());
Sonar s_left_sonar_2("left_sonar_2", kLeftTrig2Pin, kLeftEcho2Pin, &s_app.module_system(),
                     s_garage_vg, &s_app.ha_discovery());
Sonar s_right_sonar_2("right_sonar_2", kRightTrig2Pin, kRightEcho2Pin, &s_app.module_system(),
                      s_garage_vg, &s_app.ha_discovery());

Pir s_pir("pir", "motion", &s_app.module_system(), kPirPin, "motion", s_garage_vg, true, true);

// SHTC3 temperature and humidity sensor.
Shtc3 s_shtc3("temperature", "humidity", &s_app.module_system(), "temperature", s_garage_vg);

// OLED display.
Oled s_oled("oled", &s_app.module_system(), kSoftware);

constexpr int kRelayOnMsec = 500;  // was 10000;
const long kMqttUpdateMsec = 60 * kMsecInSec;

class Classifier : public Module {
 public:
  Classifier(HAApp* app, const char* side, Relay* relay, MappedAnalogSensor* light,
             VariableGroup& vg)
      : Module(side, &app->module_system()),
        m_relay(relay),
        m_light(light),
        m_side(side),
        m_door_name(String(side) + "_door"),
        m_car("car", false, "car", vg),
        m_door("door", false, "door", vg),
        m_prob_open("probOpen", 0.0f, "probability", "prob open", 0, 2, vg),
        m_prob_car("probCar", 0.0f, "probability", "prob car", 0, 2, vg),
        m_prob_empty("probEmpty", 0.0f, "probability", "prob empty", 0, 2, vg),
        m_hmm(&app->log()) {
    require(MqttManager::kName, &m_mqtt_manager);
    require(HADiscovery::kName, &m_ha_discovery);
    add_init_fn([this]() {
      loadModel();
      updateProbs();
      auto addEntry = [this](HADiscovery::Entry& entry, HADiscovery* had, JsonDocument* json) {
        char device_id[80];
        char entry_name[128];
        snprintf(device_id, sizeof(device_id), "%s_%s", had->deviceId(), m_door_name.c_str());
        snprintf(entry_name, sizeof(entry_name), "%s_%s", m_door_name.c_str(), entry.var.name());
        entry.device_name = this->m_door_name.c_str();
        entry.device_id = device_id;
        entry.via_device = had->deviceId();
        entry.entry_name = entry_name;
        return had->addEntry(json, entry);
      };

      if (m_mqtt_manager && m_ha_discovery) {
        m_ha_discovery->addDiscoveryCallback(
            [this, addEntry](HADiscovery* had, JsonDocument* json) {
              HADiscovery::Entry entry(m_door, ha::device_type::kCover,
                                       ha::device_class::cover::kGarage);
              String command = String(m_door.name()) + "/set";
              entry.command = command.c_str();
              entry.command_callback = [this](const char* topic, const char* payload, size_t len) {
                const bool on =
                    (0 == strncmp(payload, "ON", len)) || (0 == strncmp(payload, "on", len)) ||
                    (0 == strncmp(payload, "1", len)) || (0 == strncmp(payload, "OPEN", len)) ||
                    (0 == strncmp(payload, "CLOSE", len));
                if (on) {
                  m_relay->turnOn(kRelayOnMsec);
                }
              };
              return addEntry(entry, had, json);
            });
        m_ha_discovery->addDiscoveryCallback(
            [this, addEntry](HADiscovery* had, JsonDocument* json) {
              HADiscovery::Entry entry(m_car, ha::device_type::kBinarySensor,
                                       ha::device_class::binary_sensor::kPresence);
              entry.icon = "mdi:car";
              return addEntry(entry, had, json);
            });
        m_ha_discovery->addDiscoveryCallback(
            [this, addEntry](HADiscovery* had, JsonDocument* json) {
              HADiscovery::Entry entry(m_prob_open, ha::device_type::kSensor, nullptr);
              entry.icon = "mdi:gauge";
              return addEntry(entry, had, json);
            });
        m_ha_discovery->addDiscoveryCallback(
            [this, addEntry](HADiscovery* had, JsonDocument* json) {
              HADiscovery::Entry entry(m_prob_car, ha::device_type::kSensor, nullptr);
              entry.icon = "mdi:gauge";
              return addEntry(entry, had, json);
            });
        m_ha_discovery->addDiscoveryCallback(
            [this, addEntry](HADiscovery* had, JsonDocument* json) {
              HADiscovery::Entry entry(m_prob_empty, ha::device_type::kSensor, nullptr);
              entry.icon = "mdi:gauge";
              return addEntry(entry, had, json);
            });
        if (m_light) {
          m_ha_discovery->addDiscoveryCallback([this, addEntry](HADiscovery* had,
                                                                JsonDocument* json) {
            HADiscovery::Entry entry(m_light->mapped_value(), ha::device_type::kSensor, nullptr);
            return had->addEntry(json, entry);
          });
        }
      }
    });
  }

  void setValue(float m1, float m2) {
    if (m_hmm.isLoaded()) {
      int state;
      if (m_hmm.isDualSonar()) {
        state = m_hmm.update(m1, m2);
      } else {
        state = m_hmm.update(m1);
      }
      updateProbs();
      if (m_hmm.numStates() == 4) {
        // States: 0: open_car, 1: open_empty, 2: closed_car, 3: closed_empty
        switch (state) {
          case 0:
            set_open(true);
            set_car(true);
            break;
          case 1:
            set_open(true);
            set_car(false);
            break;
          case 2:
            set_open(false);
            set_car(true);
            break;
          case 3:
            set_open(false);
            set_car(false);
            break;
        }
      } else {
        // Fallback for 3-state model: 0: open, 1: closed_car, 2: closed_empty
        switch (state) {
          case 0:
            set_open(true);
            break;
          case 1:
            set_open(false);
            set_car(true);
            break;
          case 2:
            set_open(false);
            set_car(false);
            break;
        }
      }
    } else {
      // Fallback to basic thresholds if model is not loaded (using only front sonar m1)
      if (m1 < 0.10) {
      } else if (m1 < 0.7) {
        set_open(true);       // 0.1 to 0.7
      } else if (m1 < 2.4) {  // 0.7 to 2.4
        set_open(false);
        set_car(true);
      } else if (m1 < 4) {  // 2.0 to 4.0
        set_open(false);
        set_car(false);
      }
    }
  }

  void loadModel() {
    char path[32];
    snprintf(path, sizeof(path), "/hmm_%s.json", m_side.c_str());
    m_hmm.load(path);
  }
  bool isModelLoaded() const { return m_hmm.isLoaded(); }

  bool doorOpen() const { return m_door.value(); }
  bool carPresent() const { return m_car.value(); }
  const std::vector<float>& probabilities() const { return m_hmm.probabilities(); }
  int currentState() const { return m_hmm.currentState(); }

  void forceState(int state) {
    m_hmm.setState(state);
    updateProbs();
    if (m_hmm.numStates() == 4) {
      switch (state) {
        case 0:
          set_open(true);
          set_car(true);
          break;
        case 1:
          set_open(true);
          set_car(false);
          break;
        case 2:
          set_open(false);
          set_car(true);
          break;
        case 3:
          set_open(false);
          set_car(false);
          break;
      }
    } else {
      switch (state) {
        case 0:
          set_open(true);
          break;
        case 1:
          set_open(false);
          set_car(true);
          break;
        case 2:
          set_open(false);
          set_car(false);
          break;
      }
    }
  }

  bool updated() const { return m_updated; }
  void resetUpdated() { m_updated = false; }

 protected:
  void set_car(bool car) {
    if (car == m_car.value()) {
      return;
    }
    m_car = car;
    m_updated = true;
  }
  void set_open(bool open) {
    if (open == m_door.value()) {
      return;
    }
    m_door = open;
    m_updated = true;
  }

  void updateProbs() {
    const auto& probs = m_hmm.probabilities();
    if (probs.size() == 4) {
      m_prob_open = probs[0] + probs[1];
      m_prob_car = probs[0] + probs[2];
      m_prob_empty = probs[1] + probs[3];
    } else if (probs.size() == 3) {
      m_prob_open = probs[0];
      m_prob_car = probs[1];
      m_prob_empty = probs[2];
    }
  }

 private:
  Relay* m_relay;
  MappedAnalogSensor* m_light;
  String m_side;
  String m_door_name;
  BinarySensorVariable m_car;
  BinaryCoverSensorVariable m_door;
  FloatVariable m_prob_open;
  FloatVariable m_prob_car;
  FloatVariable m_prob_empty;
  HMM m_hmm;
  MqttManager* m_mqtt_manager = nullptr;
  HADiscovery* m_ha_discovery = nullptr;
  bool m_updated = false;
};

Classifier s_left_classifier(&s_app, "left", &s_left_relay, &s_light_sensor, s_left_vg);
Classifier s_right_classifier(&s_app, "right", &s_right_relay, nullptr, s_right_vg);

NetHandlerStatus handleUpload(NetRequest* request, NetResponse* response, const String& filename,
                              size_t index, uint8_t* data, size_t len, bool final) {
  static File file;
  String side = request->url().endsWith("_left") ? "left" : "right";
  String path = "/hmm_" + side + ".json";

  if (!index) {
    file = LittleFS.open(path, "w");
    if (!file) {
      s_app.log().log("Failed to open file for upload");
    }
  }
  if (file) {
    file.write(data, len);
  }
  if (final) {
    if (file) {
      file.close();
      s_app.log().log(side + " model upload complete. Reloading...");
      if (side == "left")
        s_left_classifier.loadModel();
      else
        s_right_classifier.loadModel();
    }
  }
  NET_REPLY(request, ESP_OK);
}

void update() {
  s_shtc3.read();
  s_light_sensor.read();
  s_right_sonar.setTemp(s_shtc3.temperature());
  s_left_sonar.setTemp(s_shtc3.temperature());
  s_right_sonar_2.setTemp(s_shtc3.temperature());
  s_left_sonar_2.setTemp(s_shtc3.temperature());

  s_left_sonar.read();
  delay(4);  // Wait a short (2msec) time between sonar readings.
  s_right_sonar.read();
  delay(4);
  s_left_sonar_2.read();
  delay(4);
  s_right_sonar_2.read();

  char text[256];
  // This format is currently used by the log-parser, so we need to keep it for now.
  snprintf(text, sizeof(text),
           "%.3f m %.0f usec, %.3f m %.0f usec "
           "| %.3f m %.0f usec, %.3f m %.0f usec | %.1f degf %.0f",
           s_left_sonar.distance(), s_left_sonar.ping_usec(), s_left_sonar_2.distance(),
           s_left_sonar_2.ping_usec(), s_right_sonar.distance(), s_right_sonar.ping_usec(),
           s_right_sonar_2.distance(), s_right_sonar_2.ping_usec(), s_shtc3.temperaturef(),
           s_light_sensor.value());
  s_app.log().log(text);

  snprintf(text, sizeof(text), "L:%.2fm R:%.2fm\nT:%.1fF L:%.0f%%", s_left_sonar.distance(),
           s_right_sonar.distance(), s_shtc3.temperaturef(), s_light_sensor.value());
  s_oled.display(text);

  s_pir.read();

  float right_dist2 = s_right_sonar_2.ok() ? s_right_sonar_2.distance() : -1.0f;
  float left_dist2 = s_left_sonar_2.ok() ? s_left_sonar_2.distance() : -1.0f;

  if (s_right_sonar.ok()) {
    s_right_classifier.setValue(s_right_sonar.distance(), right_dist2);
  }
  if (s_left_sonar.ok()) {
    s_left_classifier.setValue(s_left_sonar.distance(), left_dist2);
  }

  const long now_msec = millis();
  static unsigned long s_send_millis = 0;
  if (s_left_classifier.updated() || s_right_classifier.updated() ||
      (now_msec - s_send_millis) > kMqttUpdateMsec || s_send_millis == 0) {
    s_app.mqttSend(s_garage_vg);
    s_app.mqttSend(s_left_vg);
    s_app.mqttSend(s_right_vg);
    s_send_millis = now_msec;
    s_left_classifier.resetUpdated();
    s_right_classifier.resetUpdated();
  }
}

PeriodicTaskScheduler s_update_scheduler(
    4 * kMsecInSec, 2 * kMsecInSec, []() { update(); }, &s_app.tasks());

og3::WebButton s_button_left_relay(&s_app.web_server_module().native_server(), "Toggle Left Door",
                                   "/relay/left", [](NetRequest* request, NetResponse* response) {
                                     s_left_relay.turnOn(500);
                                     og3::sendWrappedHTML(request, response, "relay", "",
                                                          "Left door toggled.");
                                     NET_REPLY(request, ESP_OK);
                                   });
og3::WebButton s_button_right_relay(&s_app.web_server_module().native_server(), "Toggle Right Door",
                                    "/relay/right", [](NetRequest* request, NetResponse* response) {
                                      s_right_relay.turnOn(500);
                                      og3::sendWrappedHTML(request, response, "relay", "",
                                                           "Right door toggled.");
                                      NET_REPLY(request, ESP_OK);
                                    });
og3::WebButton s_button_wifi_config = s_app.createWifiConfigButton();
og3::WebButton s_button_mqtt_config = s_app.createMqttConfigButton();
og3::WebButton s_button_app_status = s_app.createAppStatusButton();
og3::WebButton s_button_restart = s_app.createRestartButton();

NetHandlerStatus handleWebRoot(NetRequest* request, NetResponse* response) {
  s_shtc3.read();
  String html;
  html::writeTableInto(&html, s_garage_vg);
  html::writeTableInto(&html, s_left_vg);
  html::writeTableInto(&html, s_right_vg);
  html::writeTableInto(&html, s_app.wifi_manager().variables());
  html::writeTableInto(&html, s_app.mqtt_manager().variables());
  html += "<h3>HMM Models</h3>";
  html += "<p>Left Model: ";
  html += s_left_classifier.isModelLoaded() ? "Loaded" : "Not Loaded";
  html += " | Right Model: ";
  html += s_right_classifier.isModelLoaded() ? "Loaded" : "Not Loaded";
  html += "</p>";

  html += "<form method='POST' action='/upload_left' enctype='multipart/form-data'>";
  html += "Left: <input type='file' name='model'><input type='submit' value='Upload Left'>";
  html += "</form>";

  html += "<form method='POST' action='/upload_right' enctype='multipart/form-data'>";
  html += "Right: <input type='file' name='model'><input type='submit' value='Upload Right'>";
  html += "</form>";

  s_button_left_relay.add_button(&html);
  s_button_right_relay.add_button(&html);
  s_button_wifi_config.add_button(&html);
  s_button_mqtt_config.add_button(&html);
  s_button_app_status.add_button(&html);
  s_button_restart.add_button(&html);
  sendWrappedHTML(request, response, s_app.board_cname(), kSoftware, html.c_str());
  NET_REPLY(request, ESP_OK);
}

void onMotion() {
  s_app.mqttSend(s_garage_vg);
  if (s_pir.motion()) {
    s_app.log().log("Motion detected!");
    s_oled.display("Motion");
  }
}

void checkMotion() {
  bool changed = false;
  static bool wasMotion = false;
  s_pir.read();
  const bool motion = s_pir.motion();
  changed = changed || (wasMotion != motion);
  if (changed) {
    onMotion();
  }
  wasMotion = motion;
}

// Add a watchdog to reboot the device if it locks-up for some reason.
WifiWatchdog s_watchdog(&s_app, std::chrono::seconds(5), std::chrono::seconds(1));

static String s_body;

NetHandlerStatus apiGetWifi(NetRequest* request, NetResponse* response) {
  JsonDocument jsondoc;
  JsonObject json = jsondoc.to<JsonObject>();
  s_app.wifi_manager().variables().toJson(json, VariableBase::kConfig);
  s_body.clear();
  serializeJson(jsondoc, s_body);
  response->send(200, "application/json", s_body.c_str());
  NET_REPLY(request, ESP_OK);
}

NetHandlerStatus putWifiConfig(NetRequest* request, NetResponse* response, JsonVariant& jsonIn) {
  if (!jsonIn.is<JsonObject>()) {
    response->send(500, "text/plain", "not a json object");
    NET_REPLY(request, ESP_FAIL);
  }
  JsonObject obj = jsonIn.as<JsonObject>();
  s_app.wifi_manager().variables().updateFromJson(obj);
  s_app.config().write_config(s_app.wifi_manager().variables());
  response->send(200, "text/plain", "ok");
  s_app.tasks().runIn(1000, []() { ESP.restart(); });
  NET_REPLY(request, ESP_OK);
}

NetHandlerStatus apiGetMqtt(NetRequest* request, NetResponse* response) {
  JsonDocument jsondoc;
  JsonObject json = jsondoc.to<JsonObject>();
  s_app.mqtt_manager().variables().toJson(json, VariableBase::kConfig);
  s_body.clear();
  serializeJson(jsondoc, s_body);
  response->send(200, "application/json", s_body.c_str());
  NET_REPLY(request, ESP_OK);
}

NetHandlerStatus putMqttConfig(NetRequest* request, NetResponse* response, JsonVariant& jsonIn) {
  if (!jsonIn.is<JsonObject>()) {
    response->send(500, "text/plain", "not a json object");
    NET_REPLY(request, ESP_FAIL);
  }
  JsonObject obj = jsonIn.as<JsonObject>();
  s_app.mqtt_manager().variables().updateFromJson(obj);
  s_app.config().write_config(s_app.mqtt_manager().variables());
  if (s_app.mqtt_manager().isEnabled() && !s_app.mqtt_manager().isConnected()) {
    s_app.mqtt_manager().connect();
  } else if (!s_app.mqtt_manager().isEnabled() && s_app.mqtt_manager().isConnected()) {
    s_app.mqtt_manager().disconnect();
  }
  response->send(200, "text/plain", "ok");
  NET_REPLY(request, ESP_OK);
}
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
void loop() {
  og3::s_app.loop();
  og3::checkMotion();
}

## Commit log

2024-09-27 Garage133: initial import (#1)
    [box.scad, box_bottom.stl, box_top.stl]
2024-09-28 Update OpenSCAD model, add KiCAD design (#2)
    [Garage133.csv, Garage133.kicad_pcb, Garage133.kicad_sch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]
2024-12-31 update workflows (#4)
    [ball_and_socket.scad, box.scad, box_bottom.scad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]
2025-12-14 Update to og3 0.4.0 (#7)
    - Each garage door now is a separate device, with the Garage133 the
    parent device.
    - Added a watchdog, so that if the device gets hung, it reboots in 5
    seconds.
    [Garage133_test.scad, ball_and_socket.scad, board.scad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]
2025-12-20 device_class -> 'garage_door' (was 'garage') (#9)
2025-12-26 device type -> cover, device class -> garage (#10)
2026-02-22 build update (#12)
    [Garage133_test.scad, ball_and_socket.scad, board.scad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]
2026-07-21 Bump actions/setup-python from 6 to 7 (#24)
    Bumps [actions/setup-python](https://github.com/actions/setup-python)
    from 6 to 7.
    <details>
    <summary>Release notes</summary>
    <p><em>Sourced from <a
    href="https://github.com/actions/setup-python/releases">actions/setup-python's
    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
2026-08-21 four-sonar board (#25)
    The four-sonar board written about in [Dual Sonar ESP32 Garage State
    Estimation](https://selectiveappeal.org/posts/garage133-dual-sonar/).
    - Board supports front and back sonars for both right and left garage
    bays.
    - Software update for dual-observation hmm, training update.
    - Distinct states for door open with car present and not present.
    - Updated ebox design, sencil fixture
    - Updated device web interface
    [Garage133.csv, Garage133.kicad_pcb, Garage133.kicad_sch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]
2026-10-23 Version 2.1.0: four sonars, USB-C (#26)
    ## [2.1.0] - 2026-10-14
    ### Added
    - **Hardware Board v3.1 & Enclosure Updates**: KiCAD PCB updates for
    board v3.1 with revised BOM, updated 3D printable enclosure (better
    SHTC3 thermal isolation, labeled connectors, improved USB-C port
    clearance), and solder stencil support frame model.
    - **HMM Visualization & Retraining Workflow**: Added
    `analysis/hmm_to_svg.py` to generate SVG state transition diagrams from
    trained HMM models, and added characterization workflow in
    `analysis/retrain.py`.
    ### Changed
    - **Sonar Watchdog & Timeout Stability**: Added sonar ping timeout
    handling to prevent blocking pulses from triggering the ESP32 hardware
    watchdog.
    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
